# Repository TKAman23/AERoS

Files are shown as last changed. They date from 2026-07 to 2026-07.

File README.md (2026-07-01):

# AERoS
## An All-Encompassing Rocket System

[]()

A high-performance, compact rocket flight controller board designed around the **STM32F411RET6** microcontroller. This board integrates power management, sensor telemetry, state logging, and servo control into a single-cell Li-Po powered solution optimized for model rocketry and high-altitude aerospace tracking.

## **CRITICAL DISCLAIMER:**
*This board is currently in the active development phase. It has been fully routed and designed, but it has **NOT** been physically manufactured or bench-tested yet.*

## Board Previews & Renders

*(No 3D-models for L1, L2, and L3 were available)*

| Front 3D Render | Back 3D Render |
| :---: | :---: |
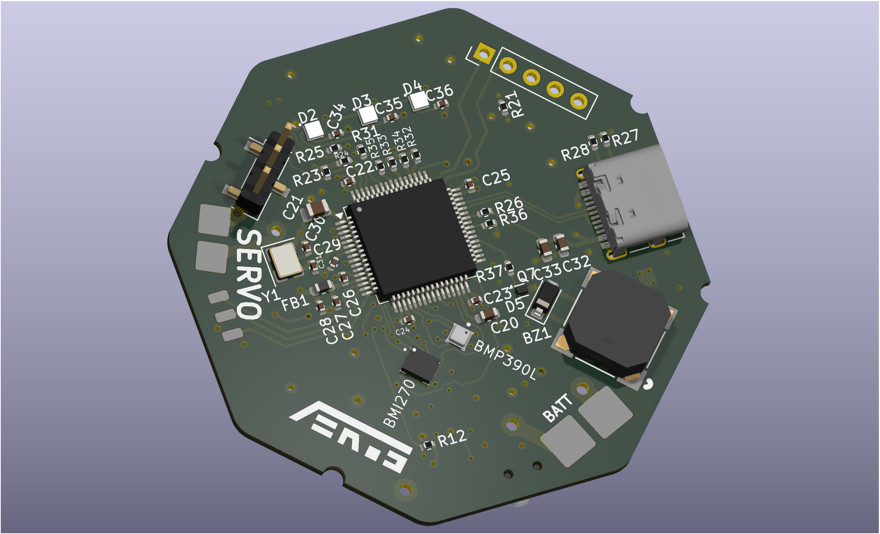
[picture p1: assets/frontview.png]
Board Front
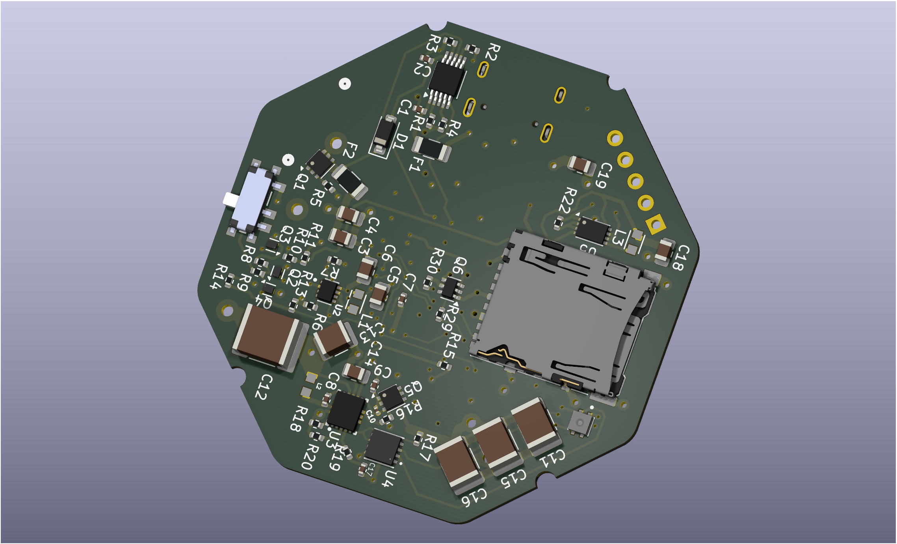
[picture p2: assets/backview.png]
Board Back
| <!-- Replace with your front render path e.g., ![Board Front](assets/front_render.png) -->  | <!-- Replace with your back render path e.g., ![Board Back](assets/back_render.png) -->  |

---

## 🛠Hardware & Board Specifications

### Core Processing & Power System
* **Microcontroller:** STM32F411RET6 (ARM Cortex-M4, 100MHz, 512KB Flash, 128KB SRAM).
* **Power Source:** Designed explicitly for a **Single-Cell Lithium-Polymer (Li-Po)** battery (~3.7V–4.2V).
* **USB Interface:** USB-C 2.0 interface supporting both data communication and **on-board USB battery charging**.
* **Power Switch:** Featuring a **self-latching MOSFET-based power switch** to enable digital soft-on/soft-off control or mechanical/pyrotechnic separation deployment triggers.
* **Actuator Power:** Integrated **Step-up (Boost) Converter** dedicated to delivering stable, elevated voltages required for servo actuation.

### Peripherals & User Interface
* **Indicators:** 3x Addressable/Configurable **RGB LEDs** for real-time state indication (e.g., pre-flight, armed, error, data logging active).
* **Acoustic Telemetry:** On-board **Piezo Buzzer** for audible flight readiness chirps, continuity checks, and recovery beacons.
* **Storage:** **D3AT SD Card Slot** wired via high-speed interface for high-rate blackbox flight logging.
* **Debugging:** Dedicated **ST-Link Connector** for SWD programming, flashing, and real-time debugging.

---

### System Architecture
<!-- Space for top-level or sheet-specific schematic screenshots as they relate to system blocks -->
```
   +-----------------------------------------------------------------+
   |                        USB-C 2.0 / Charger                      |
   +-----------------------------------------------------------------+
        |                           |
        v                           v
   +-------+           +-------------------------+           +-------+
   | Battery| ------>  | Self-Latching MOSFET SW |  -------> | Regs  |
   +-------+           +-------------------------+           +-------+
                                                                 |
            +-----------------------+------------+---------------|
            |                                    |               v
            v                                    v       +---------------+
   +-----------------+                  +------------+   | Servo Boost   |
   | STM32F411RET6   | <--- SPI/I2C --- | Sensor Bus |   +---------------+
   | Microcontroller |                  +------------+           |
   +-----------------+------+                                    v
    |      |        |       | ---------------------------> [ Servo Pins ]
    v      v        v       v
  [LEDs][Buzzer][SD Card][ST-Link]
```
For schematics, open the project file through KiCad 9.0 (can be found in the `board` directory)

<!-- #### Schematic Insights -->
<!-- <!-- Replace the placeholders below with cropped screenshots of your multi-sheet KiCad schematics -->
<!-- * **Power Management Sheet:** * *Includes USB charging circuit, battery protection, self-latching MOSFET stage, and the servo boost regulator.* -->
<!--     * <!-- ![Power Sheet](assets/schematic_power.png) --> **[Insert Power & Latching Schematic Screenshot Here]** -->
<!-- * **MCU & Breakouts Sheet:** -->
<!--     * *Includes STM32 pinouts, crystal oscillators, decoupling capacitors, and ST-Link header.* -->
<!--     * <!-- ![MCU Sheet](assets/schematic_mcu.png) --> **[Insert MCU Core Schematic Screenshot Here]** -->

---

## On-Board Sensors

The sensor suite communicates over optimized I2C/SPI buses to provide highly accurate 9-DOF inertial, environmental, and barometric data.

| Sensor Part Number | Type | Primary Flight Function |
| :--- | :--- | :--- |
| **BMI270** | 6-Axis IMU (Accel/Gyro) | Rocket orientation, acceleration profiling, launch detection, and apogee sensing. |
| **BMP390L** | High-Precision Barometer | Precise altitude tracking, descent-rate monitoring, and main/drogue parachute deployment triggering. |
| **SHTC3** | Humidity & Temp Sensor | Environmental monitoring and internal enclosure/payload bay diagnostics. |

---

## Design & Development

* **EDA Software:** Designed completely using **KiCad**.
* **Firmware Compatibility:** Perfect pairing with STM32CubeIDE, HAL libraries, or custom bare-metal C/C++ architectures.

### Future Scope / Additions (To-Do)
- [ ] Physical PCB manufacturing and assembly (PCBA evaluation).
- [ ] Continuity testing on the self-latching MOSFET network.
- [ ] Bench testing the Step-Up regulator under maximum servo load.
- [ ] Developing a comprehensive flight firmware stack (Blackbox logging framework, Kalman filtering for apogee detection).
- [ ] Pinout map cheat-sheet (Markdown table matching STM32 pins to hardware blocks).

---

## License & Copyright

This project is licensed under the **GNU GPL v3** License. 

```
Copyright (c) 2026 Karthikeya Turimalla (TKAman23)

This program is free software: you can redistribute it and/or modify
it under the terms of the GNU General Public License as published by
the Free Software Foundation, either version 3 of the License, or
(at your option) any later version.
```
See the accompanying `LICENSE` file for full terms and conditions.

---

## Attribution Request

If you use parts of this repository, please reference the repository, my username (TKAman23), or me (Karthikeya Turimalla) in your work.

---

## Contributing & Feedback

Since this project is in active prototyping, discussions, issues, and pull requests regarding optimization (especially around power management and thermal layout) are generally welcome!
Contact: [karthikeyaat@gmail.com](mailto:karthikeyaat@gmail.com).

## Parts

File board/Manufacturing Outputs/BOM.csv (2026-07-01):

Comment | Designator | Footprint | JLCPCB Part #
MLT-8530 | BZ1 | CustomLibrary2:MLT-8530_JHE | C94599
1u | C1,C2,C27,C28 | Capacitor_SMD:C_0402_1005Metric | C14445
4u7 | C3,C4,C14,C18 | Capacitor_SMD:C_0805_2012Metric | C1779
10u | C5,C6,C19,C21 | Capacitor_SMD:C_0805_2012Metric | C15850
100n | C7,C8,C9,C22,C23,C24,C25,C29 | Capacitor_SMD:C_0402_1005Metric | C1525
22n | C10 | Capacitor_SMD:C_0201_0603Metric | C285066
47u | C11,C15,C16 | Capacitor_SMD:C_1812_4532Metric | C342615
100u | C12 | Capacitor_SMD:C_2220_5750Metric | C76692
22u | C13 | Capacitor_SMD:C_1210_3225Metric | C52306
1n | C17 | Capacitor_SMD:C_0402_1005Metric | C1523
2u2 | C20 | Capacitor_SMD:C_0603_1608Metric | C23630
10n | C26 | Capacitor_SMD:C_0402_1005Metric | C1524
30p | C30,C31 | Capacitor_SMD:C_0402_1005Metric | C1570
10u | C32 | Capacitor_SMD:C_0603_1608Metric | C1691
4u7 | C33 | Capacitor_SMD:C_0603_1608Metric | C1705
220n | C34,C35,C36 | Capacitor_SMD:C_0402_1005Metric | C16772
SD101CW-E3-18 | D1,D5 | Diode_SMD:D_SOD-123 | C3313033
SK6805 | D2,D3,D4 | CustomLibrary2:SK6805-EC15 | C2890035
600m | F1 | Fuse:Fuse_1206_3216Metric | C2154056
500m | F2 | Fuse:Fuse_1206_3216Metric | C20798
GZ1608D121TF | FB1 | Inductor_SMD:L_0603_1608Metric | C12391
MountingHole | H1,H2,H3,H4 | MountingHole:MountingHole_2.2mm_M2
Conn_01x01_Pin | J1,J2 | CustomLibrary2:Pad_4x4mm
Conn_01x01_Pin | J3,J4 | CustomLibrary2:Pad_3x3mm
Conn_01x01_Pin | J5,J6,J7 | Connector_Wire:SolderWirePad_1x01_SMD_1x2mm
Conn_01x03_Pin | J8 | Connector_PinHeader_2.54mm:PinHeader_1x03_P2.54mm_Vertical_SMD_Pin1Left | C5160786
USB_C_Receptacle_USB2.0_14P | J9 | Connector_USB:USB_C_Receptacle_G-Switch_GT-USB-7010ASV | C2988369
Conn_01x05_Pin | J10 | Connector_PinHeader_2.54mm:PinHeader_1x05_P2.54mm_Vertical
SD Card Hirose DM3AT | J11 | Connector_Card:microSD_HC_Hirose_DM3AT-SF-PEJM5 | C114218
2u2 | L1,L3 | CustomLibrary2:IND_LQH2MPZ2R2MGRL | C2042050
1u | L2 | CustomLibrary2:0806 | C702824
PMOS | Q1,Q5 | CustomLibrary2:DFN-6-2EP_(AGM20P16AS) | C18221388
NMOS | Q2,Q3,Q4,Q7 | CustomLibrary2:DFN-3(0.6x1) | C20605534
NMOS | Q6 | Package_TO_SOT_SMD:SOT-363_SC-70-6 | C15215
1k | R1,R5,R8,R9,R23,R24,R29,R30,R32,R33,R34,R35,R36 | Resistor_SMD:R_0402_1005Metric | C11702
10k | R2,R3,R31 | Resistor_SMD:R_0402_1005Metric | C25744
1k5 | R4 | Resistor_SMD:R_0402_1005Metric | C25867
100k | R6,R11,R12,R13,R15,R26 | Resistor_SMD:R_0402_1005Metric | C25741
267k | R7 | Resistor_SMD:R_0402_1005Metric | C270622
100 | R10 | Resistor_SMD:R_0402_1005Metric | C25076
365k | R14 | Resistor_SMD:R_0402_1005Metric | C27006
121k | R16 | Resistor_SMD:R_0402_1005Metric | C11693
536k | R17 | Resistor_SMD:R_0402_1005Metric | C68457
300k | R18 | Resistor_SMD:R_0402_1005Metric | C25774
44k2 | R19 | Resistor_SMD:R_0402_1005Metric | C25895
78k7 | R20 | Resistor_SMD:R_0402_1005Metric | C67239
976k | R21 | Resistor_SMD:R_0402_1005Metric | C25802
562k | R22 | Resistor_SMD:R_0402_1005Metric | C48838
50k | R25 | Resistor_SMD:R_0402_1005Metric | C166559
5k1 | R27,R28 | Resistor_SMD:R_0402_1005Metric | C25905
470 | R37 | Resistor_SMD:R_0402_1005Metric | C25117
SW_SPDT | SW1 | CustomLibrary2:MK-12C02-G020_GSW | C963206
BQ24090DGQ | U1 | Package_SO:HVSSOP-10-1EP_3x3mm_P0.5mm_EP1.57x1.88mm_ThermalVias | C43306
TPS62840DLCR | U2 | CustomLibrary2:SON50P200X150X100-8N | C2071859
TPS611781RNWR | U3 | Custom_Library:RNW0013A | C2862009
MCP4552T-104E/MF | U4 | CustomLibrary2:DFN8_3x3MC_MCH | C623602
MCP1640x-xMC | U5 | Package_DFN_QFN:DFN-8-1EP_3x2mm_P0.5mm_EP1.75x1.45mm | C623037
STM32F411RET6 | U6 | Package_QFP:LQFP-64_10x10mm_P0.5mm | C94355
BMI270 | U7 | Custom_Library:XDCR_BMI270 | C2836813
BMP390L | U8 | Custom_Library:XDCR_BMP390L | C2684802
SHTC3 | U9 | Custom_Library:SON100P200X200X80-5N | C194656
16M | Y1 | Crystal:Crystal_SMD_3225-4Pin_3.2x2.5mm | C5452684

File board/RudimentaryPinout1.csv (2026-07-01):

Position | Name | Type | Signal | Label
1 | VBAT | Power
2 | PC13-ANTI_TAMP | I/O
3 | PC14-OSC32_IN | I/O
4 | PC15-OSC32_OUT | I/O
5 | PH0 - OSC_IN | I/O | RCC_OSC_IN
6 | PH1 - OSC_OUT | I/O | RCC_OSC_OUT
7 | NRST | Reset
8 | PC0 | I/O | ADC1_IN10
9 | PC1 | I/O
10 | PC2 | I/O
11 | PC3 | I/O
12 | VSSA | Power
13 | VDDA | Power
14 | PA0-WKUP | I/O | TIM2_CH1
15 | PA1 | I/O | TIM2_CH2
16 | PA2 | I/O | TIM2_CH3
17 | PA3 | I/O
18 | VSS | Power
19 | VDD | Power
20 | PA4 | I/O
21 | PA5 | I/O | SPI1_SCK
22 | PA6 | I/O | SPI1_MISO
23 | PA7 | I/O | SPI1_MOSI
24 | PC4 | I/O
25 | PC5 | I/O
26 | PB0 | I/O
27 | PB1 | I/O
28 | PB2 | I/O
29 | PB10 | I/O
30 | VCAP1 | Power
31 | VSS | Power
32 | VDD | Power
33 | PB12 | I/O
34 | PB13 | I/O
35 | PB14 | I/O
36 | PB15 | I/O
37 | PC6 | I/O | TIM3_CH1
38 | PC7 | I/O | TIM3_CH2
39 | PC8 | I/O | SDIO_D0
40 | PC9 | I/O | SDIO_D1
41 | PA8 | I/O
42 | PA9 | I/O | USB_OTG_FS_VBUS
43 | PA10 | I/O
44 | PA11 | I/O | USB_OTG_FS_DM
45 | PA12 | I/O | USB_OTG_FS_DP
46 | PA13 | I/O | SYS_JTMS-SWDIO
47 | VSS | Power
48 | VDD | Power
49 | PA14 | I/O | SYS_JTCK-SWCLK
50 | PA15 | I/O
51 | PC10 | I/O | SDIO_D2
52 | PC11 | I/O | SDIO_D3
53 | PC12 | I/O | SDIO_CK
54 | PD2 | I/O | SDIO_CMD
55 | PB3 | I/O
56 | PB4 | I/O
57 | PB5 | I/O
58 | PB6 | I/O | I2C1_SCL
59 | PB7 | I/O | I2C1_SDA
60 | BOOT0 | Boot
61 | PB8 | I/O
62 | PB9 | I/O
63 | VSS | Power
64 | VDD | Power

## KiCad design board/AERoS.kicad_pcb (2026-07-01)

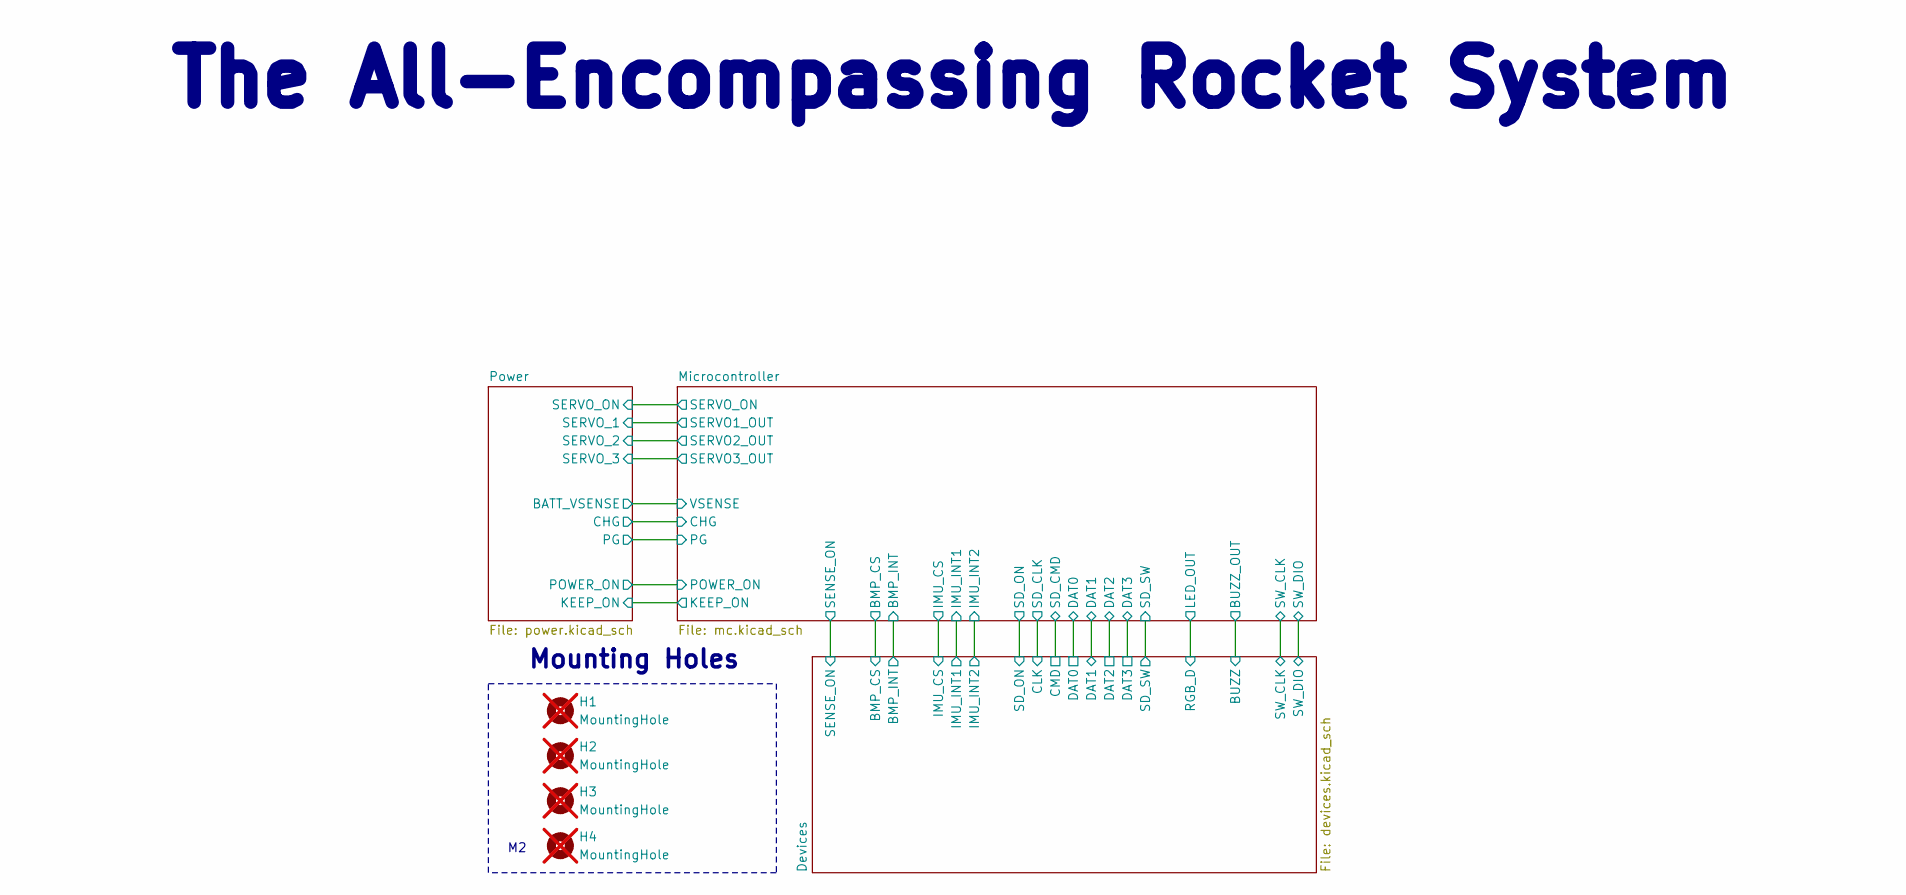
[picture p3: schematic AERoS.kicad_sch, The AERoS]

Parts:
H1, H2, H3, H4: MountingHole; MountingHole_2.2mm_M2; not fitted

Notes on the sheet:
Mounting Holes
The All-Encompassing Rocket System

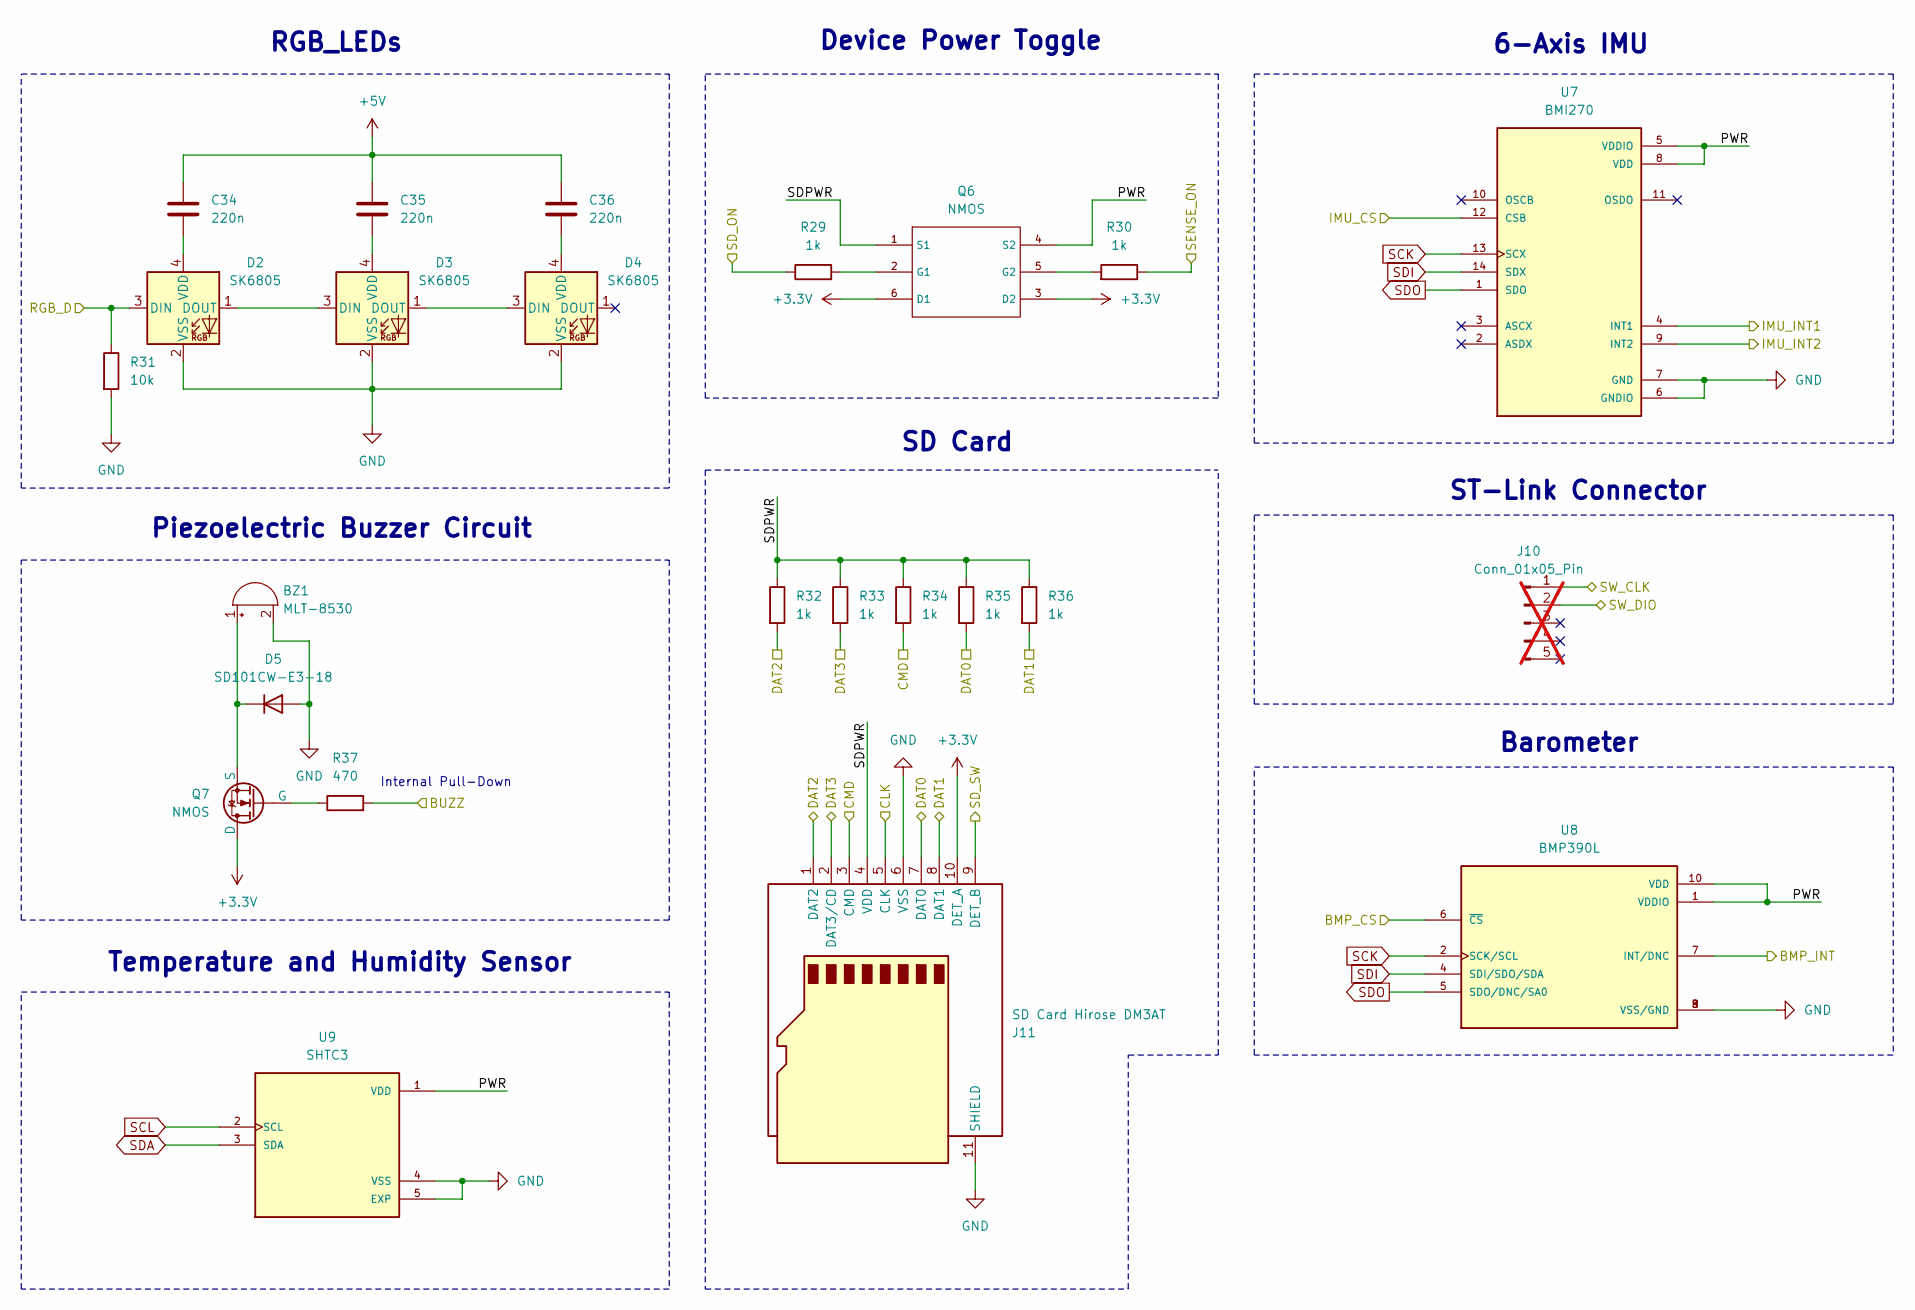
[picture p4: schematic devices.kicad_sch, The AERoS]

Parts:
BZ1: MLT-8530; MLT-8530_JHE; MFR. Part # MLT-8530; JLCPCB Part # C94599
C34, C35, C36: 220n; C_0402_1005Metric; MFR. Part # CL05B224KO5NNNC; JLCPCB Part # C16772
D2, D3, D4: SK6805; SK6805-EC15; MFR. Part # SK6805-EC15; JLCPCB Part # C2890035
D5: SD101CW-E3-18; D_SOD-123; MFR. Part # SD101CW-E3-18; JLCPCB Part # C3313033
J10: Conn_01x05_Pin; PinHeader_1x05_P2.54mm_Vertical; not fitted
J11: SD Card Hirose DM3AT; microSD_HC_Hirose_DM3AT-SF-PEJM5; MFR. Part # DM3AT-SF-PEJM5; JLCPCB Part # C114218
Q6: NMOS; SOT-363_SC-70-6; MFR. Part # NTJD5121NT1G; JLCPCB Part # C15215
Q7: NMOS; DFN-3(0.6x1); MFR. Part # YJA3134KB; JLCPCB Part # C20605534
R29, R30, R32, R33, R34, R35, R36: 1k; R_0402_1005Metric; MFR. Part # 0402WGF1001TCE; JLCPCB Part # C11702
R31: 10k; R_0402_1005Metric; MFR. Part # 0402WGF1002TCE; JLCPCB Part # C25744
R37: 470; R_0402_1005Metric; MFR. Part # 0402WGF4700TCE; JLCPCB Part # C25117
U7: BMI270; XDCR_BMI270; MFR. Part # BMI270; JLCPCB Part # C2836813
U8: BMP390L; XDCR_BMP390L; PARTREV 1.7; JLCPCB Part # C2684802
U9: SHTC3; SON100P200X200X80-5N; PARTREV 3; JLCPCB Part # C194656

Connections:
+3.3V: J11.10 (DET_A), Q6.3 (D2), Q6.6 (D1), Q7.1 (D); also elsewhere on the board
+5V: C34.1, C35.1, C36.1; also elsewhere on the board
/Devices/BMP_CS: U8.6 (~CS); also elsewhere on the board
/Devices/BMP_INT: U8.7 (INT/DNC); also elsewhere on the board
/Devices/BUZZ: R37.2; also elsewhere on the board
/Devices/CLK: J11.5 (CLK); also elsewhere on the board
/Devices/CMD: J11.3 (CMD), R34.2; also elsewhere on the board
/Devices/DAT0: J11.7 (DAT0), R35.2; also elsewhere on the board
/Devices/DAT1: J11.8 (DAT1), R36.2; also elsewhere on the board
/Devices/DAT2: J11.1 (DAT2), R32.2; also elsewhere on the board
/Devices/DAT3: J11.2 (DAT3/CD), R33.2; also elsewhere on the board
/Devices/IMU_CS: U7.12 (CSB); also elsewhere on the board
/Devices/IMU_INT1: U7.4 (INT1); also elsewhere on the board
/Devices/IMU_INT2: U7.9 (INT2); also elsewhere on the board
/Devices/PWR: Q6.4 (S2), U7.5 (VDDIO), U7.8 (VDD), U8.1 (VDDIO), U8.10 (VDD), U9.1 (VDD)
/Devices/RGB_D: D2.3 (DIN), R31.1; also elsewhere on the board
/Devices/SDPWR: J11.4 (VDD), Q6.1 (S1), R32.1, R33.1, R34.1, R35.1, R36.1
/Devices/SD_ON: R29.1; also elsewhere on the board
/Devices/SD_SW: J11.9 (DET_B); also elsewhere on the board
/Devices/SENSE_ON: R30.1; also elsewhere on the board
/Devices/SW_CLK: J10.1; also elsewhere on the board
/Devices/SW_DIO: J10.2; also elsewhere on the board
GND: BZ1.2 (-), D2.2 (VSS), D3.2 (VSS), D4.2 (VSS), D5.2 (A), J11.6 (VSS), J11.11 (SHIELD), R31.2, U7.6 (GNDIO), U7.7 (GND), U8.3 (VSS/GND), U8.8 (VSS/GND), U8.9 (VSS/GND), U9.4 (VSS), U9.5 (EXP); also elsewhere on the board
unnamed: BZ1.1 (+), D5.1 (K), Q7.3 (S)
unnamed: D2.1 (DOUT), D3.3 (DIN)
unnamed: C34.2, D2.4 (VDD)
unnamed: D3.1 (DOUT), D4.3 (DIN)
unnamed: C35.2, D3.4 (VDD)
unnamed: C36.2, D4.4 (VDD)
unnamed: Q6.2 (G1), R29.2
unnamed: Q6.5 (G2), R30.2
unnamed: Q7.2 (G), R37.1
SCK: U7.13 (SCX), U8.2 (SCK/SCL); also elsewhere on the board
SCL: U9.2 (SCL); also elsewhere on the board
SDA: U9.3 (SDA); also elsewhere on the board
SDI: U7.14 (SDX), U8.4 (SDI/SDO/SDA); also elsewhere on the board
SDO: U7.1 (SDO), U8.5 (SDO/DNC/SA0); also elsewhere on the board

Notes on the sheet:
RGB_LEDs
6-Axis IMU
Internal Pull-Down
Device Power Toggle
Barometer
Piezoelectric Buzzer Circuit
Temperature and Humidity Sensor
SD Card
ST-Link Connector

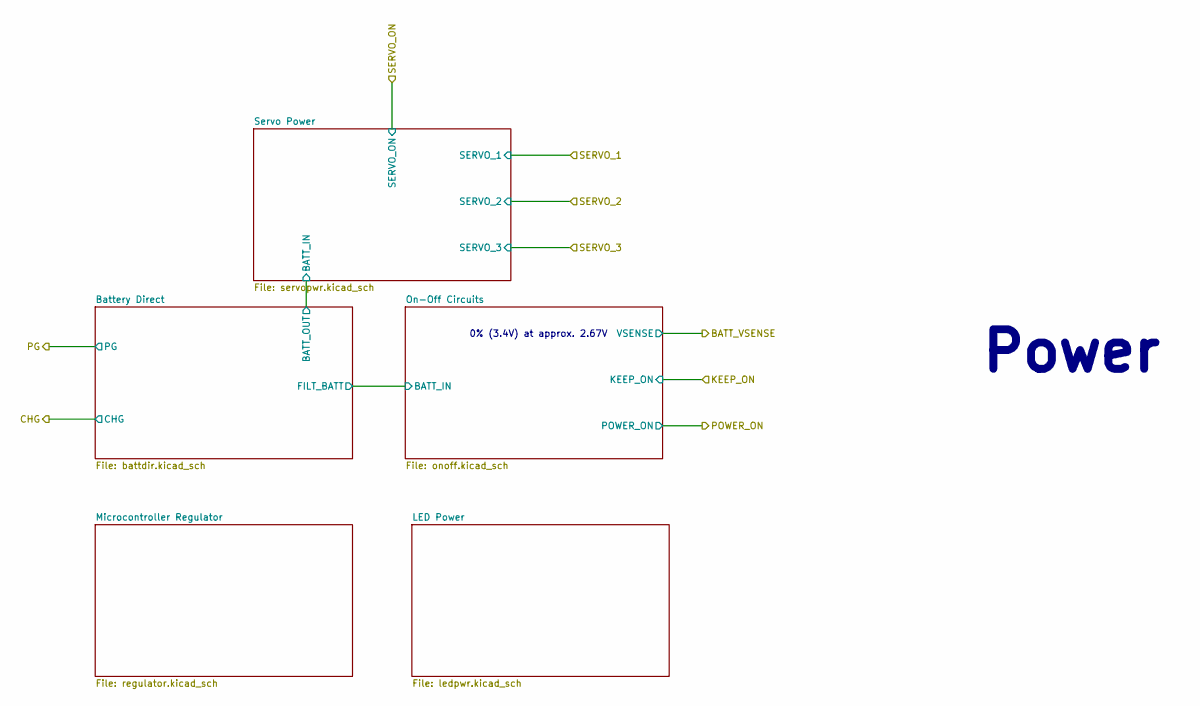
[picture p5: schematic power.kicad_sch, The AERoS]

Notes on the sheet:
Power
0% (3.4V) at approx. 2.67V

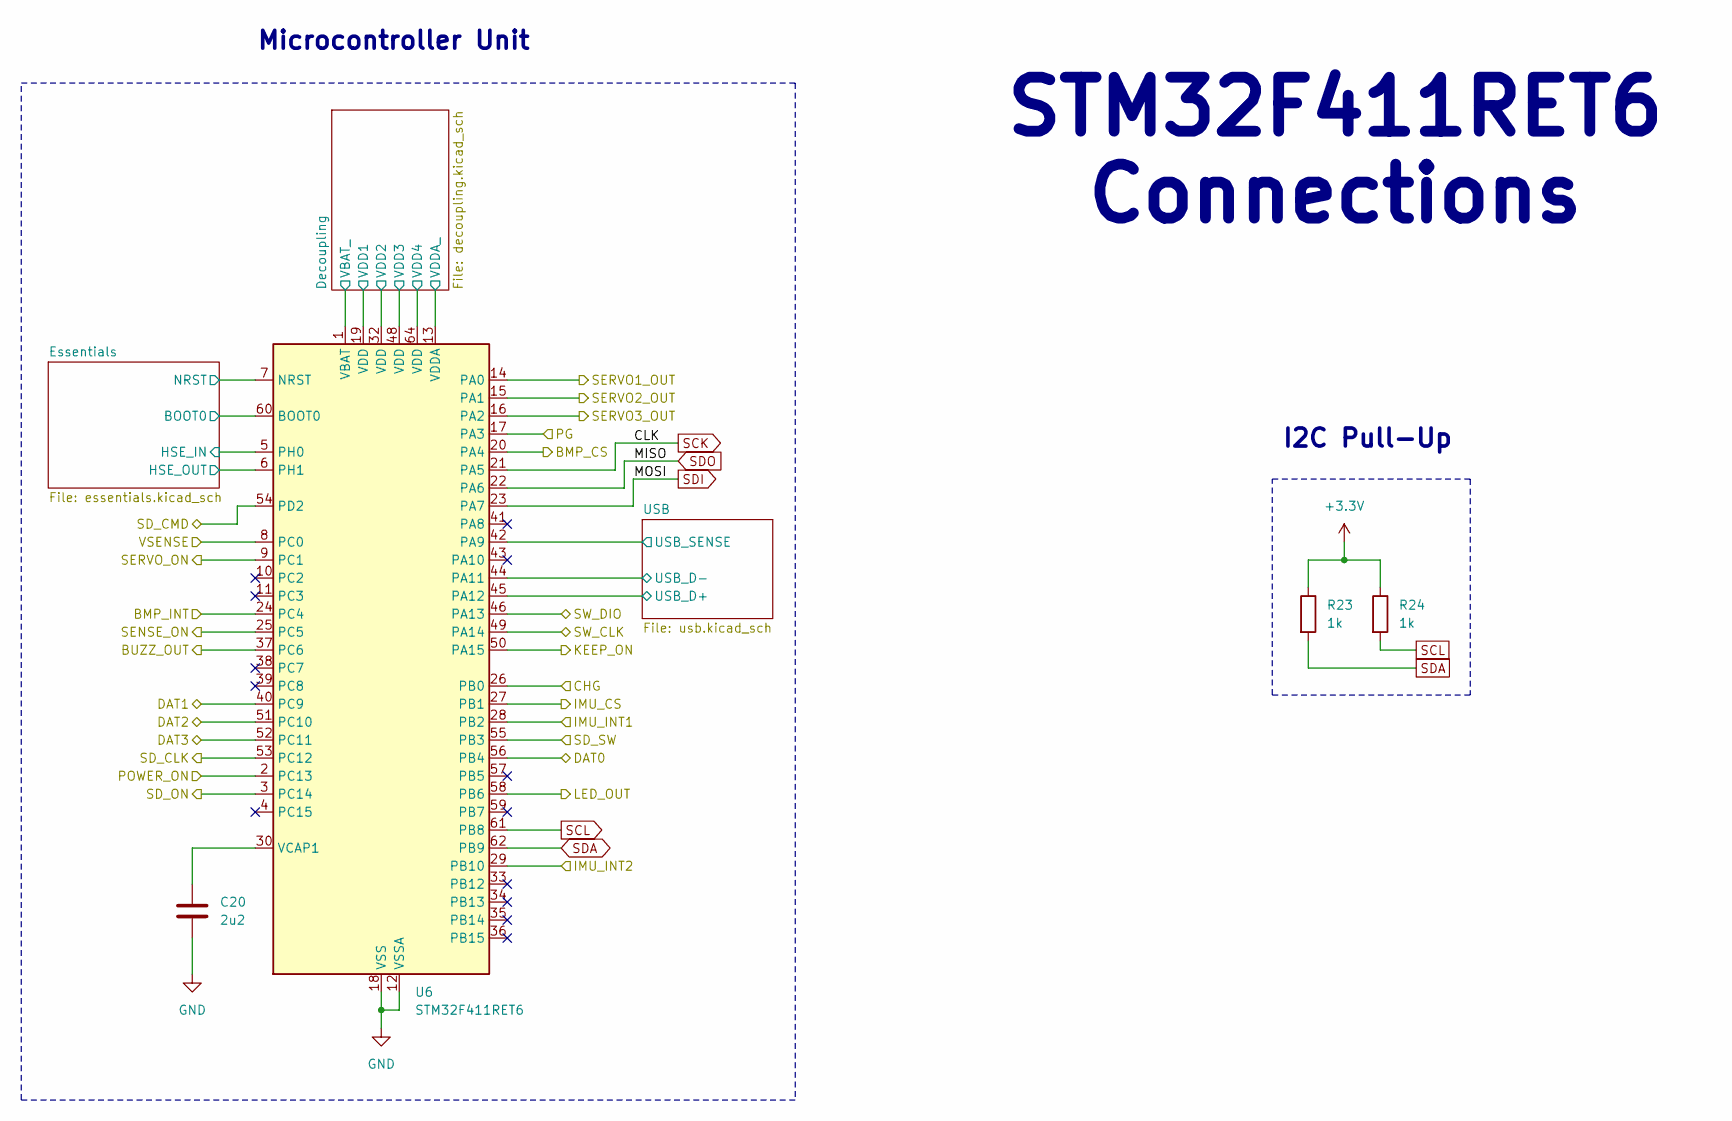
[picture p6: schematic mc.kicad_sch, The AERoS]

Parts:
C20: 2u2; C_0603_1608Metric; MFR. Part # CL10A225KO8NNNC; JLCPCB Part # C23630
R23, R24: 1k; R_0402_1005Metric; MFR. Part # 0402WGF1001TCE; JLCPCB Part # C11702
U6: STM32F411RET6; LQFP-64_10x10mm_P0.5mm; MFR. Part # STM32F411RET6; JLCPCB Part # C94355

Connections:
+3.3V: R23.1, R24.1, U6.1 (VBAT), U6.19 (VDD), U6.32 (VDD), U6.48 (VDD), U6.64 (VDD); also elsewhere on the board
/Devices/BMP_CS: U6.20 (PA4); also elsewhere on the board
/Devices/BMP_INT: U6.24 (PC4); also elsewhere on the board
/Devices/BUZZ: U6.37 (PC6); also elsewhere on the board
/Devices/CLK: U6.53 (PC12); also elsewhere on the board
/Devices/CMD: U6.54 (PD2); also elsewhere on the board
/Devices/DAT0: U6.56 (PB4); also elsewhere on the board
/Devices/DAT1: U6.40 (PC9); also elsewhere on the board
/Devices/DAT2: U6.51 (PC10); also elsewhere on the board
/Devices/DAT3: U6.52 (PC11); also elsewhere on the board
/Devices/IMU_CS: U6.27 (PB1); also elsewhere on the board
/Devices/IMU_INT1: U6.28 (PB2); also elsewhere on the board
/Devices/IMU_INT2: U6.29 (PB10); also elsewhere on the board
/Devices/RGB_D: U6.58 (PB6); also elsewhere on the board
/Devices/SD_ON: U6.3 (PC14); also elsewhere on the board
/Devices/SD_SW: U6.55 (PB3); also elsewhere on the board
/Devices/SENSE_ON: U6.25 (PC5); also elsewhere on the board
/Devices/SW_CLK: U6.49 (PA14); also elsewhere on the board
/Devices/SW_DIO: U6.46 (PA13); also elsewhere on the board
/Microcontroller/CHG: U6.26 (PB0); also elsewhere on the board
/Microcontroller/Decoupling/VDDA_: U6.13 (VDDA); also elsewhere on the board
/Microcontroller/Essentials/BOOT0: U6.60 (BOOT0); also elsewhere on the board
/Microcontroller/Essentials/HSE_IN: U6.5 (PH0); also elsewhere on the board
/Microcontroller/Essentials/HSE_OUT: U6.6 (PH1); also elsewhere on the board
/Microcontroller/Essentials/NRST: U6.7 (NRST); also elsewhere on the board
/Microcontroller/KEEP_ON: U6.50 (PA15); also elsewhere on the board
/Microcontroller/PG: U6.17 (PA3); also elsewhere on the board
/Microcontroller/POWER_ON: U6.2 (PC13); also elsewhere on the board
/Microcontroller/SERVO1_OUT: U6.14 (PA0); also elsewhere on the board
/Microcontroller/SERVO2_OUT: U6.15 (PA1); also elsewhere on the board
/Microcontroller/SERVO3_OUT: U6.16 (PA2); also elsewhere on the board
/Microcontroller/SERVO_ON: U6.9 (PC1); also elsewhere on the board
/Microcontroller/USB/USB_D+: U6.45 (PA12); also elsewhere on the board
/Microcontroller/USB/USB_D-: U6.44 (PA11); also elsewhere on the board
/Microcontroller/USB/USB_SENSE: U6.42 (PA9); also elsewhere on the board
/Microcontroller/VSENSE: U6.8 (PC0); also elsewhere on the board
GND: C20.2, U6.12 (VSSA), U6.18 (VSS), U6.31 (VSS), U6.47 (VSS), U6.63 (VSS); also elsewhere on the board
unnamed: C20.1, U6.30 (VCAP1)
SCK: U6.21 (PA5); also elsewhere on the board
SCL: R24.2, U6.61 (PB8); also elsewhere on the board
SDA: R23.2, U6.62 (PB9); also elsewhere on the board
SDI: U6.23 (PA7); also elsewhere on the board
SDO: U6.22 (PA6); also elsewhere on the board

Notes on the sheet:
I2C Pull-Up
Microcontroller Unit
STM32F411RET6 Connections

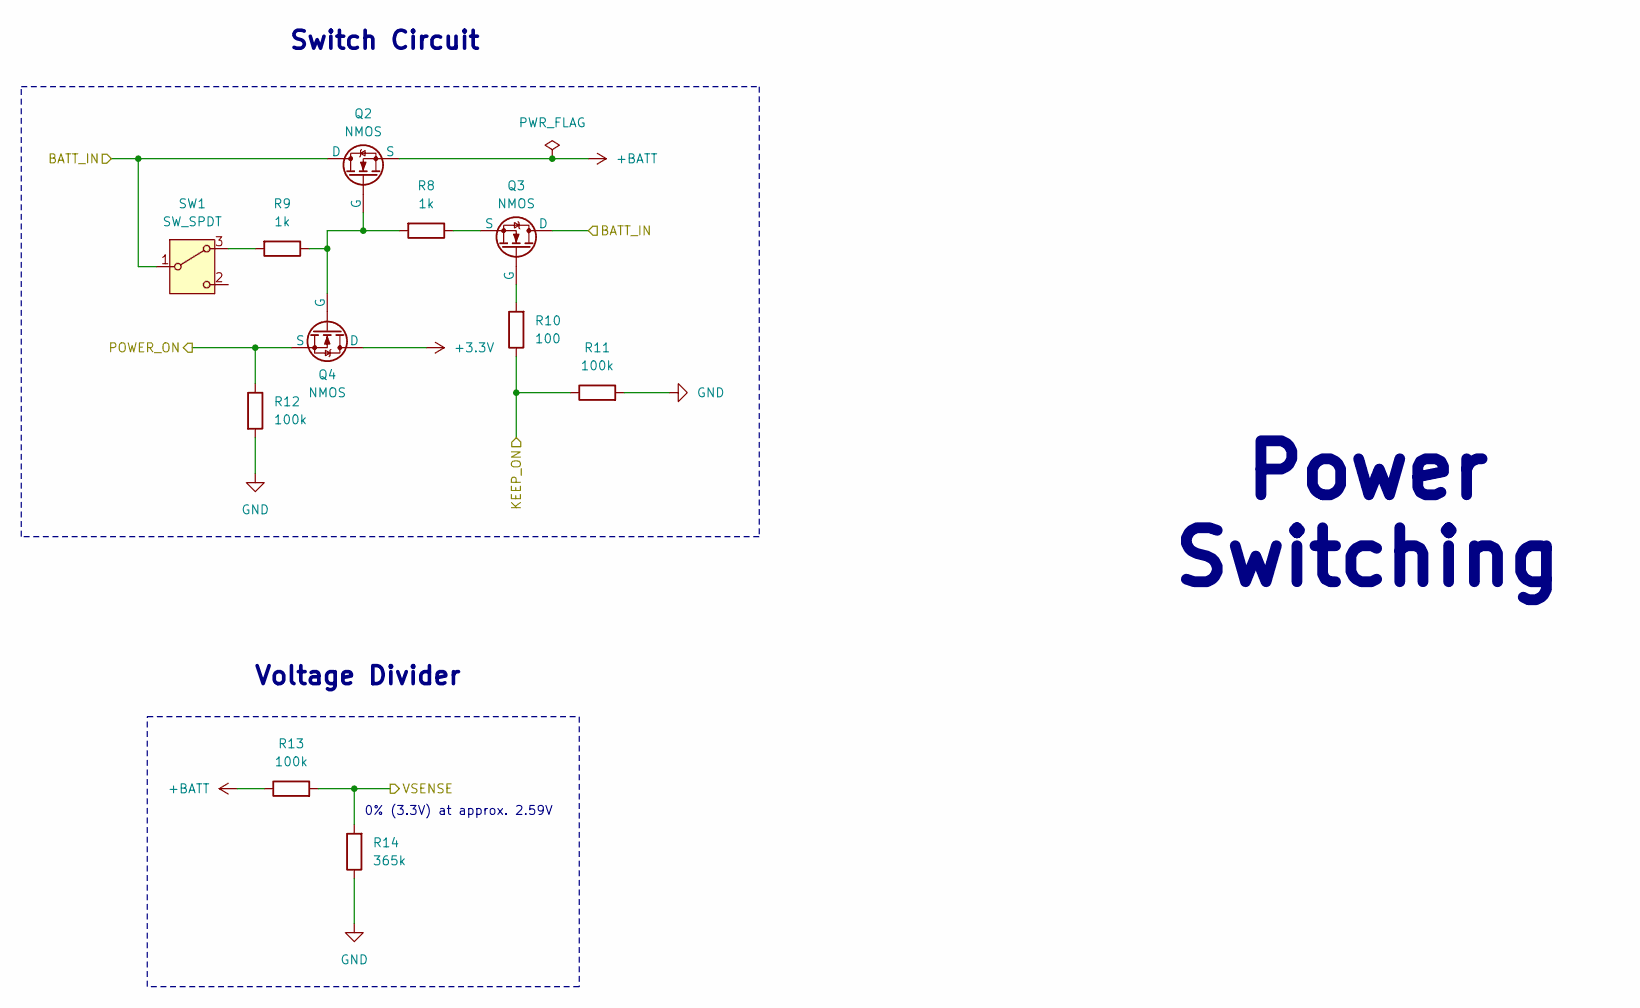
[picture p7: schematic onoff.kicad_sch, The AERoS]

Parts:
Q2, Q3, Q4: NMOS; DFN-3(0.6x1); MFR. Part # YJA3134KB; JLCPCB Part # C20605534
R8, R9: 1k; R_0402_1005Metric; MFR. Part # 0402WGF1001TCE; JLCPCB Part # C11702
R10: 100; R_0402_1005Metric; MFR. Part # 0402WGF1000TCE; JLCPCB Part # C25076
R11, R12, R13: 100k; R_0402_1005Metric; MFR. Part # 0402WGF1003TCE; JLCPCB Part # C25741
R14: 365k; R_0402_1005Metric; MFR. Part # 0402WGF3653TCE; JLCPCB Part # C27006
SW1: SW_SPDT; MK-12C02-G020_GSW; MFR. Part # MK-12C02-G020_GSW; JLCPCB Part # C963206

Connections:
+3.3V: Q4.1 (D); also elsewhere on the board
+BATT: Q2.3 (S), R13.1; also elsewhere on the board
/Microcontroller/KEEP_ON: R10.1, R11.1; also elsewhere on the board
/Microcontroller/POWER_ON: Q4.3 (S), R12.1; also elsewhere on the board
/Microcontroller/VSENSE: R13.2, R14.2; also elsewhere on the board
/Power/Battery Direct/FILT_BATT: Q2.1 (D), Q3.1 (D), SW1.1 (B); also elsewhere on the board
GND: R11.2, R12.2, R14.1; also elsewhere on the board
unnamed: Q2.2 (G), Q4.2 (G), R8.2, R9.1
unnamed: Q3.2 (G), R10.2
unnamed: Q3.3 (S), R8.1
unnamed: R9.2, SW1.3 (A)

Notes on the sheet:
Power Switching
0% (3.3V) at approx. 2.59V
Switch Circuit
Voltage Divider

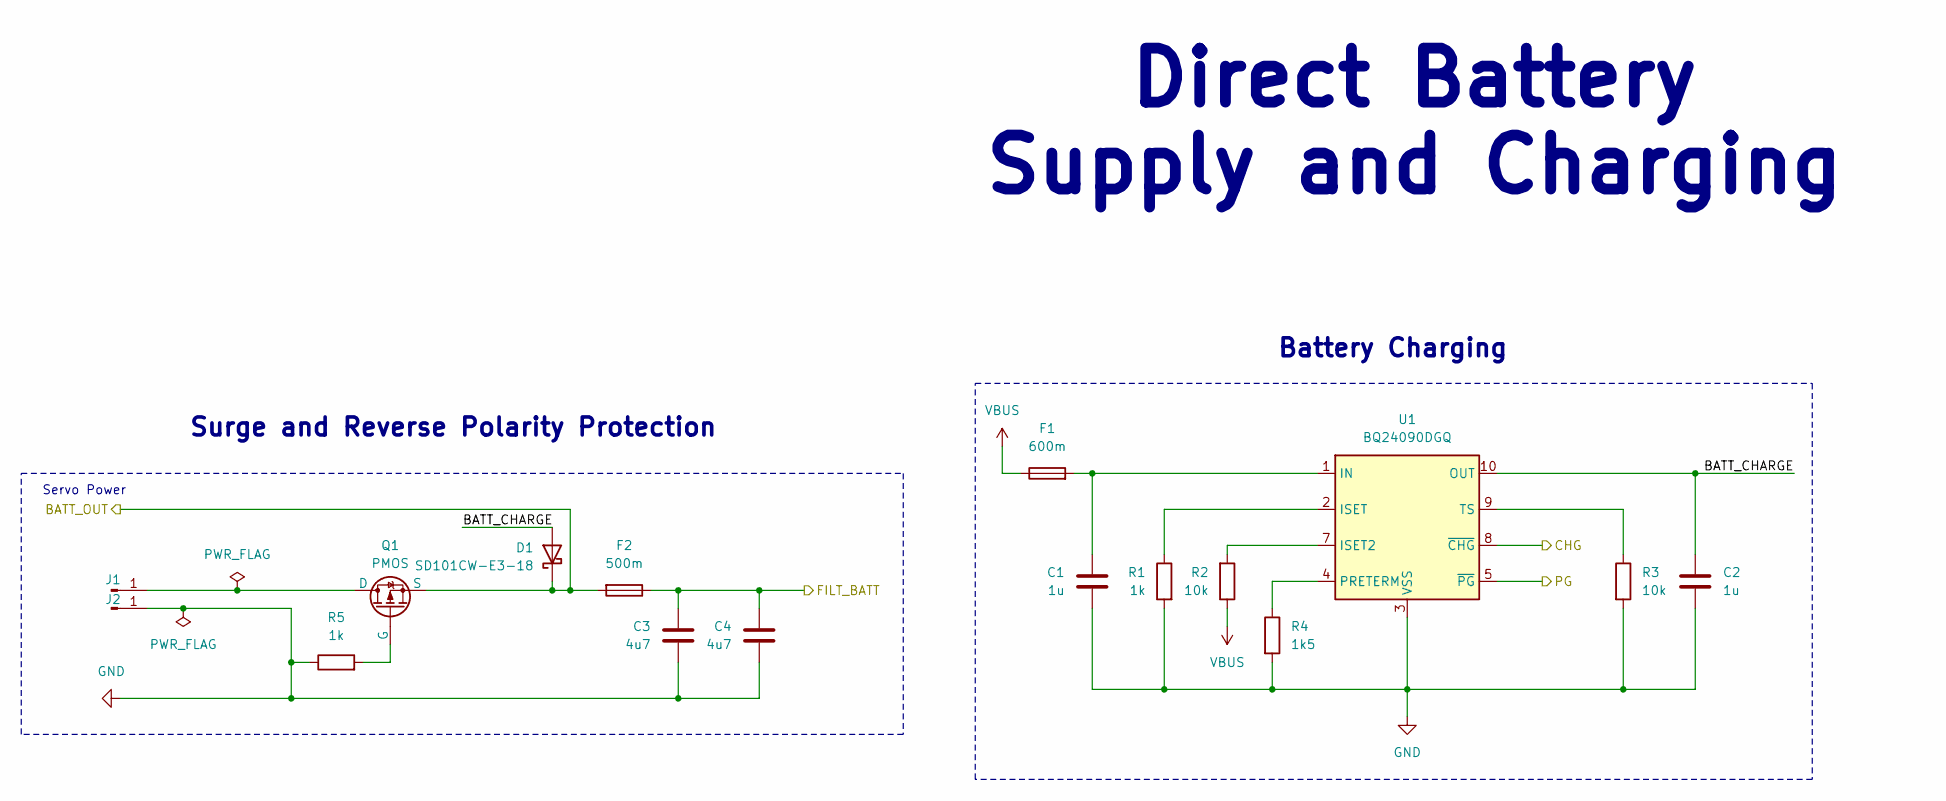
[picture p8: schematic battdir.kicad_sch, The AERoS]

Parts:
C1, C2: 1u; C_0402_1005Metric; MFR. Part # CL05A105KP5NNNC; JLCPCB Part # C14445
C3, C4: 4u7; C_0805_2012Metric; MFR. Part # CL21A475KAQNNNE; JLCPCB Part # C1779
D1: SD101CW-E3-18; D_SOD-123; MFR. Part # SD101CW-E3-18; JLCPCB Part # C3313033
F1: 600m; Fuse_1206_3216Metric; MFR. Part # 1206L050/24WR; JLCPCB Part # C2154056
F2: 500m; Fuse_1206_3216Metric; MFR. Part # SMD1206P025TF; JLCPCB Part # C20798
J1, J2: Conn_01x01_Pin; Pad_4x4mm
Q1: PMOS; DFN-6-2EP_(AGM20P16AS); MFR. Part # AGM20P16AS; JLCPCB Part # C18221388
R1, R5: 1k; R_0402_1005Metric; MFR. Part # 0402WGF1001TCE; JLCPCB Part # C11702
R2, R3: 10k; R_0402_1005Metric; MFR. Part # 0402WGF1002TCE; JLCPCB Part # C25744
R4: 1k5; R_0402_1005Metric; MFR. Part # 0402WGF1501TCE; JLCPCB Part # C25867
U1: BQ24090DGQ; HVSSOP-10-1EP_3x3mm_P0.5mm_EP1.57x1.88mm_ThermalVias; MFR. Part # BQ24090DGQR; JLCPCB Part # C43306

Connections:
/Microcontroller/CHG: U1.8 (~CHG); also elsewhere on the board
/Microcontroller/PG: U1.5 (~PG); also elsewhere on the board
/Power/Battery Direct/BATT_CHARGE: C2.1, D1.2 (A), U1.10 (OUT)
/Power/Battery Direct/BATT_OUT: D1.1 (K), F2.2, Q1.3 (S); also elsewhere on the board
/Power/Battery Direct/FILT_BATT: C3.2, C4.2, F2.1; also elsewhere on the board
GND: C1.2, C2.2, C3.1, C4.1, J2.1, R1.2, R3.2, R4.2, R5.1, U1.3 (VSS), U1.11 (VSS); also elsewhere on the board
unnamed: J1.1, Q1.1 (D)
unnamed: Q1.2 (G), R5.2
unnamed: C1.1, F1.2, U1.1 (IN)
unnamed: R2.2, U1.7 (ISET2)
unnamed: R1.1, U1.2 (ISET)
unnamed: R4.1, U1.4 (PRETERM)
unnamed: R3.1, U1.9 (TS)
VBUS: F1.1, R2.1; also elsewhere on the board

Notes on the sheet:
Battery Charging
Surge and Reverse Polarity Protection
Direct Battery Supply and Charging
Servo Power

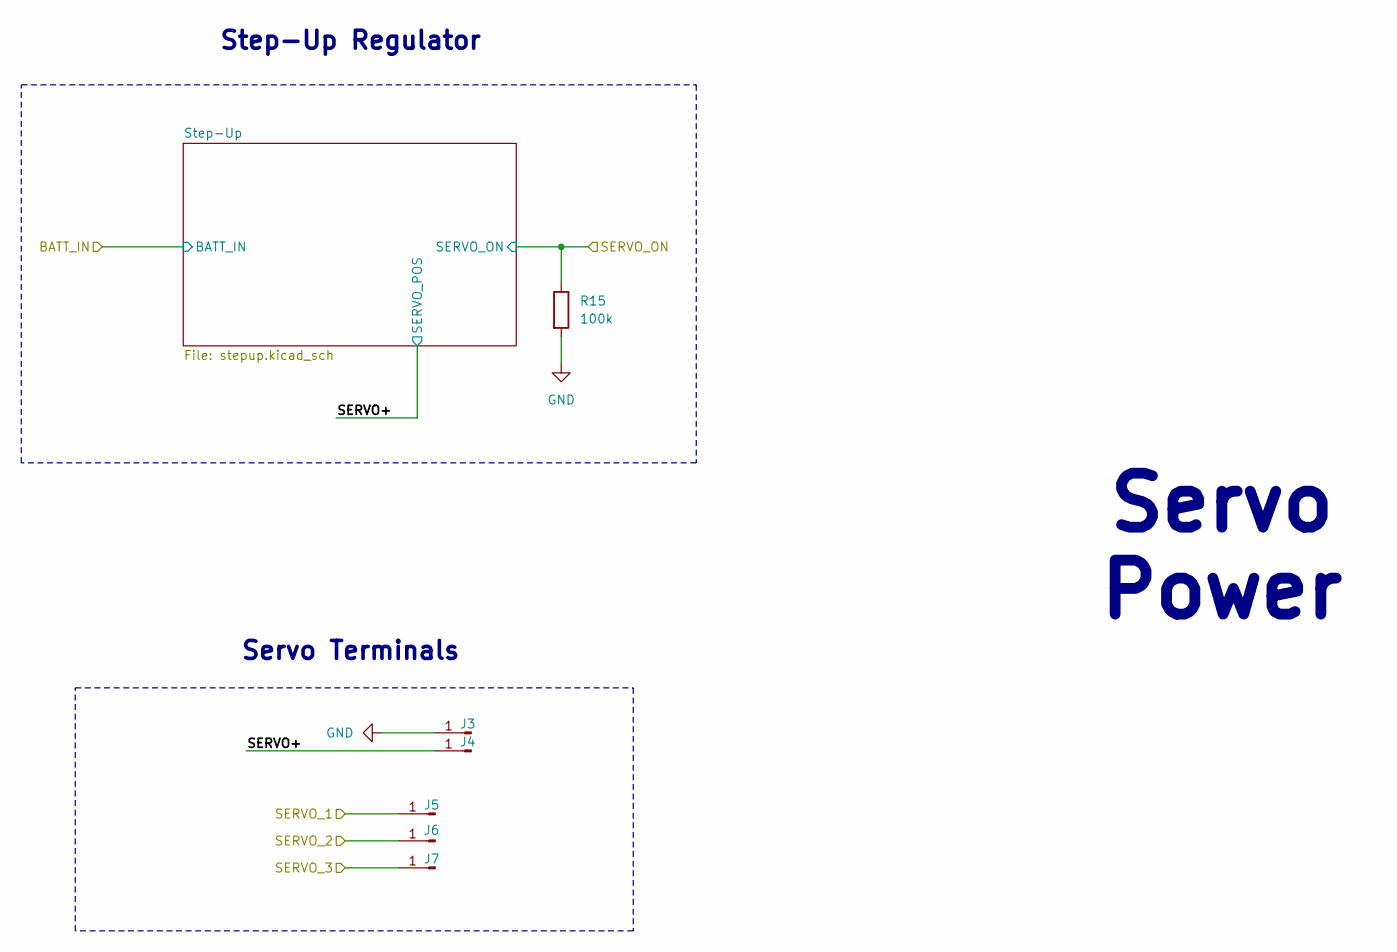
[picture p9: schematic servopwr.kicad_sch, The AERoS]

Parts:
J3, J4: Conn_01x01_Pin; Pad_3x3mm
J5, J6, J7: Conn_01x01_Pin; SolderWirePad_1x01_SMD_1x2mm
R15: 100k; R_0402_1005Metric; MFR. Part # 0402WGF1003TCE; JLCPCB Part # C25741

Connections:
/Microcontroller/SERVO1_OUT: J5.1; also elsewhere on the board
/Microcontroller/SERVO2_OUT: J6.1; also elsewhere on the board
/Microcontroller/SERVO3_OUT: J7.1; also elsewhere on the board
/Microcontroller/SERVO_ON: R15.1; also elsewhere on the board
/Power/Servo Power/SERVO+: J4.1; also elsewhere on the board
GND: J3.1, R15.2; also elsewhere on the board

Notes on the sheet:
Step-Up Regulator
Servo Power
Servo Terminals

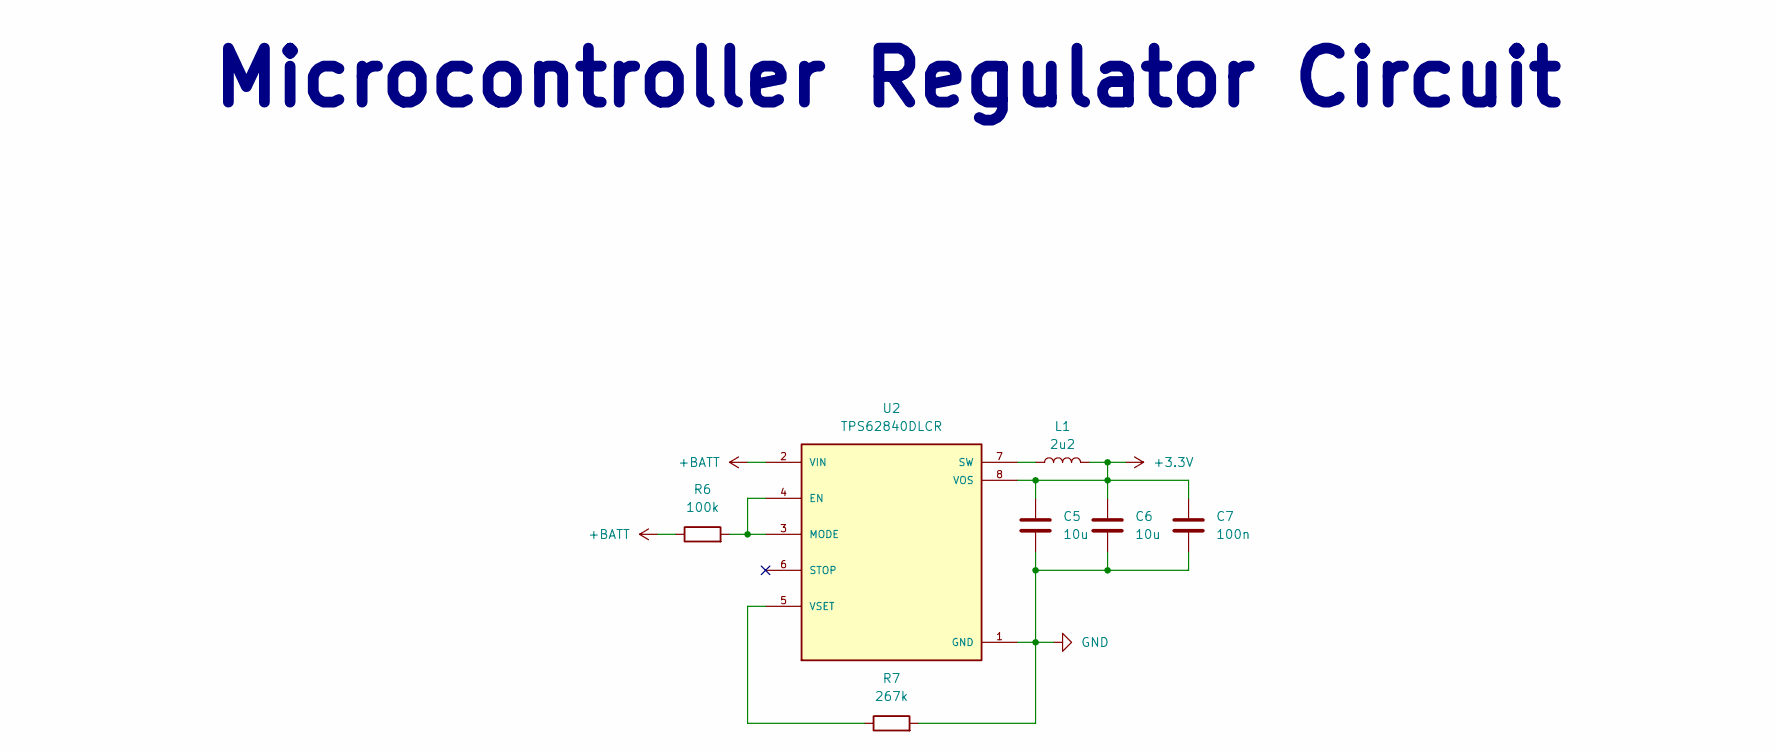
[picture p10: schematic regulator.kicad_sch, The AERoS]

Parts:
C5, C6: 10u; C_0805_2012Metric; MFR. Part # CL21A106KAYNNNE; JLCPCB Part # C15850
C7: 100n; C_0402_1005Metric; MFR. Part # CL05B104KO5NNNC; JLCPCB Part # C1525
L1: 2u2; IND_LQH2MPZ2R2MGRL; MFR. Part # LQH2MPZ2R2MGRL; JLCPCB Part # C2042050
R6: 100k; R_0402_1005Metric; MFR. Part # 0402WGF1003TCE; JLCPCB Part # C25741
R7: 267k; R_0402_1005Metric; MFR. Part # 0402WGF2673TCE; JLCPCB Part # C270622
U2: TPS62840DLCR; SON50P200X150X100-8N; MFR. Part # TPS62840DLCR; JLCPCB Part # C2071859

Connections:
+3.3V: C5.2, C6.2, C7.2, L1.2, U2.8 (VOS); also elsewhere on the board
+BATT: R6.1, U2.2 (VIN); also elsewhere on the board
GND: C5.1, C6.1, C7.1, R7.2, U2.1 (GND); also elsewhere on the board
unnamed: R6.2, U2.3 (MODE), U2.4 (EN)
unnamed: L1.1, U2.7 (SW)
unnamed: R7.1, U2.5 (VSET)

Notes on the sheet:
Microcontroller Regulator Circuit

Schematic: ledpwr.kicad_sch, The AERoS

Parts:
C18: 4u7; C_0805_2012Metric; MFR. Part # CL21A475KAQNNNE; JLCPCB Part # C1779
C19: 10u; C_0805_2012Metric; MFR. Part # CL21A106KAYNNNE; JLCPCB Part # C15850
L3: 2u2; IND_LQH2MPZ2R2MGRL; MFR. Part # LQH2MPZ2R2MGRL; JLCPCB Part # C2042050
R21: 976k; R_0402_1005Metric; MFR. Part # 0402WGF9763TCE; JLCPCB Part # C25802
R22: 562k; R_0402_1005Metric; MFR. Part # 0402WGF5623TCE; JLCPCB Part # C48838
U5: MCP1640x-xMC; DFN-8-1EP_3x2mm_P0.5mm_EP1.75x1.45mm; MFR. Part # MCP1640CT-I/MC; JLCPCB Part # C623037

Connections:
+5V: C19.1, R21.1, U5.6 (V_{OUT}), U5.7 (V_{OUT}); also elsewhere on the board
+BATT: C18.1, L3.1, U5.4 (EN), U5.8 (V_{IN}); also elsewhere on the board
GND: C18.2, C19.2, R22.2, U5.2 (GND), U5.3 (GND), U5.9 (GND); also elsewhere on the board
unnamed: L3.2, U5.5 (SW)
unnamed: R21.2, R22.1, U5.1 (V_{FB})

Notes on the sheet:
LED Power Regulator
LED Regulator

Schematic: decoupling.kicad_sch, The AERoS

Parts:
C21: 10u; C_0805_2012Metric; MFR. Part # CL21A106KAYNNNE; JLCPCB Part # C15850
C22, C23, C24, C25: 100n; C_0402_1005Metric; MFR. Part # CL05B104KO5NNNC; JLCPCB Part # C1525
C26: 10n; C_0402_1005Metric; MFR. Part # 0402B103K500NT; JLCPCB Part # C1524
C27, C28: 1u; C_0402_1005Metric; MFR. Part # CL05A105KP5NNNC; JLCPCB Part # C14445
FB1: GZ1608D121TF; L_0603_1608Metric; MFR. Part # GZ1608D121TF; JLCPCB Part # C12391

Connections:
+3.3V: C21.1, C22.1, C23.1, C24.1, C25.1, C28.1, FB1.2; also elsewhere on the board
/Microcontroller/Decoupling/VDDA_: C26.1, C27.1, FB1.1; also elsewhere on the board
GND: C21.2, C22.2, C23.2, C24.2, C25.2, C26.2, C27.2, C28.2; also elsewhere on the board

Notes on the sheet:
Analog
Decoupling Capacitors for STM32
Standard

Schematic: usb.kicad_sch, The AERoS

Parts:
C32: 10u; C_0603_1608Metric; MFR. Part # CL10A106MQ8NNNC; JLCPCB Part # C1691
C33: 4u7; C_0603_1608Metric; MFR. Part # CL10A475KP8NNNC; JLCPCB Part # C1705
J9: USB_C_Receptacle_USB2.0_14P; USB_C_Receptacle_G-Switch_GT-USB-7010ASV; MFR. Part # GT-USB-7010ASV; JLCPCB Part # C2988369
R26: 100k; R_0402_1005Metric; MFR. Part # 0402WGF1003TCE; JLCPCB Part # C25741
R27, R28: 5k1; R_0402_1005Metric; MFR. Part # 0402WGF5101TCE; JLCPCB Part # C25905

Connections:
/Microcontroller/USB/USB_D+: J9.A6 (D+), J9.B6 (D+); also elsewhere on the board
/Microcontroller/USB/USB_D-: J9.A7 (D-), J9.B7 (D-); also elsewhere on the board
/Microcontroller/USB/USB_SENSE: R26.2; also elsewhere on the board
GND: C32.2, C33.2, J9.A1 (GND), J9.A12 (GND), J9.B1 (GND), J9.B12 (GND), J9.S1 (SHIELD), R27.2, R28.2; also elsewhere on the board
unnamed: J9.A5 (CC1), R27.1
unnamed: J9.B5 (CC2), R28.1
VBUS: C32.1, C33.1, J9.A4 (VBUS), J9.A9 (VBUS), J9.B4 (VBUS), J9.B9 (VBUS), R26.1; also elsewhere on the board

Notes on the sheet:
USB
USB Connection Circuit
500mA MAX

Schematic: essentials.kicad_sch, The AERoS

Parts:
C29: 100n; C_0402_1005Metric; MFR. Part # CL05B104KO5NNNC; JLCPCB Part # C1525
C30, C31: 30p; C_0402_1005Metric; MFR. Part # 0402CG300J500NT; JLCPCB Part # C1570
J8: Conn_01x03_Pin; PinHeader_1x03_P2.54mm_Vertical_SMD_Pin1Left; MFR. Part # DZ254S-11-03-48; JLCPCB Part # C5160786
R25: 50k; R_0402_1005Metric; MFR. Part # RTT025002FTH; JLCPCB Part # C166559
Y1: 16M; Crystal_SMD_3225-4Pin_3.2x2.5mm; MFR. Part # X322516MMB4SI; JLCPCB Part # C112972

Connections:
+3.3V: J8.1; also elsewhere on the board
/Microcontroller/Essentials/BOOT0: R25.1; also elsewhere on the board
/Microcontroller/Essentials/HSE_IN: C30.1, Y1.1; also elsewhere on the board
/Microcontroller/Essentials/HSE_OUT: C31.1, Y1.3; also elsewhere on the board
/Microcontroller/Essentials/NRST: C29.2; also elsewhere on the board
/Microcontroller/Essentials/SW_BOOT0: J8.2, R25.2
GND: C29.1, C30.2, C31.2, J8.3, Y1.2, Y1.4; also elsewhere on the board

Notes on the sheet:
Booting Circuit
Crystal Oscillator
STM32 Functional Circuits

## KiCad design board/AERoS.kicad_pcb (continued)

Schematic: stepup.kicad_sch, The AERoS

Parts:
C8, C9: 100n; C_0402_1005Metric; MFR. Part # CL05B104KO5NNNC; JLCPCB Part # C1525
C10: 22n; C_0201_0603Metric; MFR. Part # 0201X223K160NT; JLCPCB Part # C285066
C11, C15, C16: 47u; C_1812_4532Metric; MFR. Part # C4532X5R1A476MT000N; JLCPCB Part # C342615
C12: 100u; C_2220_5750Metric; MFR. Part # C5750X5R1A107MT000E; JLCPCB Part # C76692
C13: 22u; C_1210_3225Metric; MFR. Part # CL32A226KAJNNNE; JLCPCB Part # C52306
C14: 4u7; C_0805_2012Metric; MFR. Part # CL21A475KAQNNNE; JLCPCB Part # C1779
C17: 1n; C_0402_1005Metric; MFR. Part # 0402B102K500NT; JLCPCB Part # C1523
L2: 1u; 0806; MFR. Part # BDHE002016081R0MQ1; JLCPCB Part # C702824
Q5: PMOS; DFN-6-2EP_(AGM20P16AS); MFR. Part # AGM20P16AS; JLCPCB Part # C18221388
R16: 121k; R_0402_1005Metric; MFR. Part # 0402WGF1213TCE; JLCPCB Part # C11693
R17: 536k; R_0402_1005Metric; MFR. Part # 0402WGF5363TCE; JLCPCB Part # C68457
R18: 300k; R_0402_1005Metric; MFR. Part # 0402WGF3003TCE; JLCPCB Part # C25774
R19: 44k2; R_0402_1005Metric; MFR. Part # 0402WGF4422TCE; JLCPCB Part # C25895
R20: 78k7; R_0402_1005Metric; MFR. Part # 0402WGF7872TCE; JLCPCB Part # C67239
U3: TPS611781RNWR; RNW0013A; MFR. Part # TPS611781RNWR; JLCPCB Part # C2862009
U4: MCP4552T-104E/MF; DFN8_3x3MC_MCH; MFR. Part # MCP4552T-104E/MF; JLCPCB Part # C623602

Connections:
+3.3V: U4.8 (VDD); also elsewhere on the board
/Microcontroller/SERVO_ON: U3.11 (EN); also elsewhere on the board
/Power/Battery Direct/BATT_OUT: C12.1, C13.1, L2.1, U3.12 (VIN); also elsewhere on the board
/Power/Servo Power/SERVO+: C11.1, C15.1, C16.1, Q5.3 (S), R17.2; also elsewhere on the board
/Power/Servo Power/Step-Up/PREPOT: R17.1, U3.5 (FB), U4.6 (P0B)
GND: C9.1, C11.2, C12.2, C13.2, C14.2, C15.2, C16.2, C17.2, R18.2, R20.2, U3.2 (AGND), U3.6 (PGND), U4.1 (HVC/A0), U4.4 (VSS), U4.5 (P0W), U4.7 (A1), U4.9 (EP); also elsewhere on the board
unnamed: C17.1, R19.2
unnamed: C9.2, C10.1, Q5.1 (D), R16.1, U3.8 (VOUT)
unnamed: C10.2, Q5.2 (G), R16.2, U3.9 (DISDRV)
unnamed: C8.2, U3.13 (BST)
unnamed: R19.1, U3.4 (COMP)
unnamed: R18.1, U3.1 (FREQ_SYNC)
unnamed: R20.1, U3.3 (ILIMIT)
unnamed: C8.1, L2.2, U3.7 (SW)
unnamed: C14.1, U3.10 (VCC)
SCL: U4.2 (SCL); also elsewhere on the board
SDA: U4.3 (SDA); also elsewhere on the board

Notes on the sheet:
6V at 78.7k ohms
Digipot
Servo Power Step-Up
Step-Up Regulator Circuit
I2C Address: 00

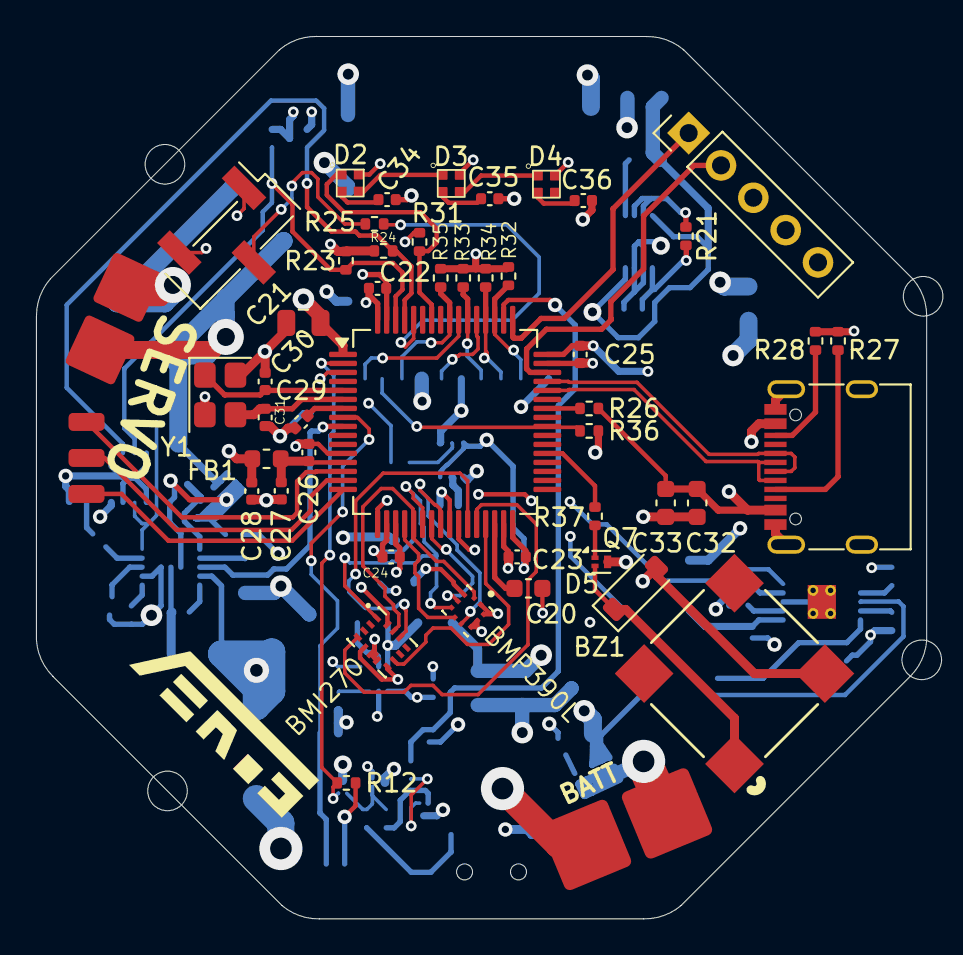
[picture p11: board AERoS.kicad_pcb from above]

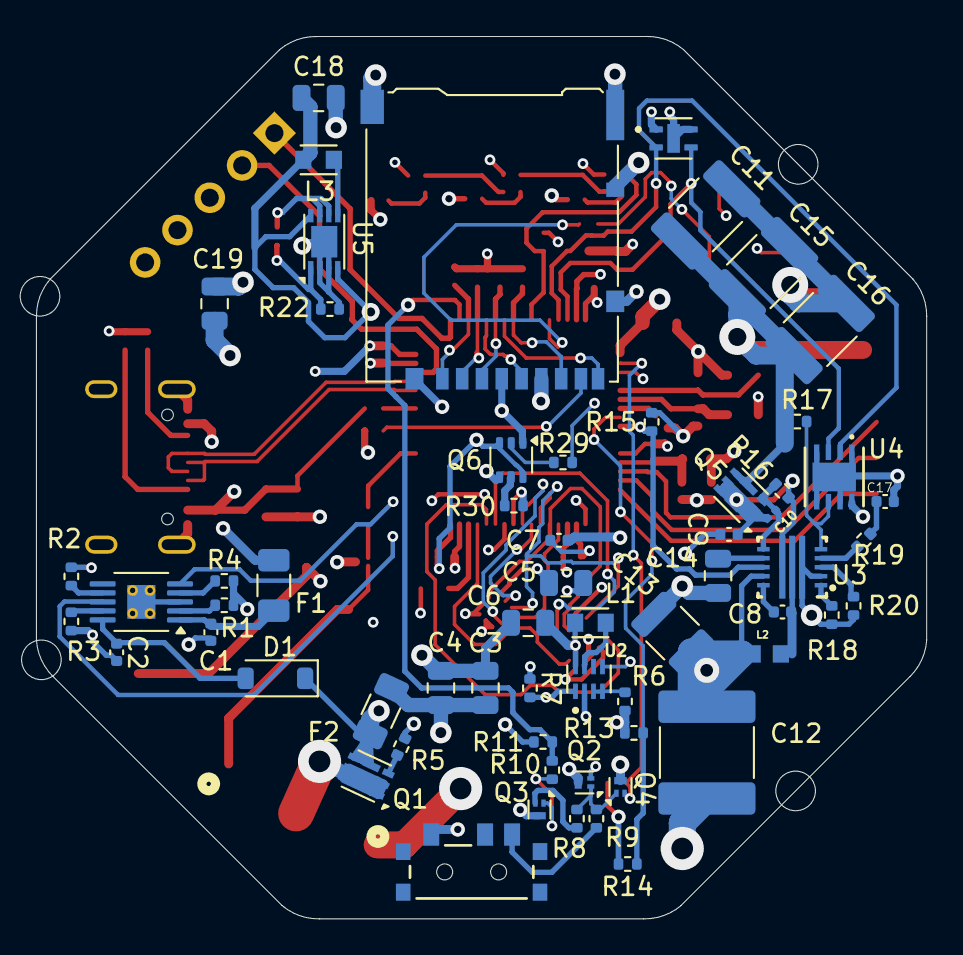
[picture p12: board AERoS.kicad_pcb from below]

Board: 4 copper layers, 49.5 x 49.0 mm, 118 parts (61 on the bottom side), 90 nets.

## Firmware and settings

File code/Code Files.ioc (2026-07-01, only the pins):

Mcu.UserName=STM32F411RETx
PA0-WKUP.GPIO_Label=SERVO1
PA0-WKUP.Signal=S_TIM2_CH1_ETR
PA1.GPIO_Label=SERVO2
PA1.Signal=S_TIM2_CH2
PA10.Signal=GPIO_Analog
PA11.GPIO_Label=USB_D-
PA11.Signal=USB_OTG_FS_DM
PA12.GPIO_Label=USB_D+
PA12.Signal=USB_OTG_FS_DP
PA13.GPIO_Label=SW_DIO
PA13.Signal=SYS_JTMS-SWDIO
PA14.GPIO_Label=SW_CLK
PA14.Signal=SYS_JTCK-SWCLK
PA15.GPIO_Label=KEEP_ON
PA15.Signal=GPIO_Output
PA2.GPIO_Label=SERVO3
PA2.Signal=S_TIM2_CH3
PA3.Signal=GPIO_Analog
PA4.GPIO_Label=BMP_CS
PA4.Signal=GPIO_Output
PA5.GPIO_Label=CLK
PA5.Signal=SPI1_SCK
PA6.GPIO_Label=MISO
PA6.Signal=SPI1_MISO
PA7.GPIO_Label=MOSI
PA7.Signal=SPI1_MOSI
PA8.Signal=GPIO_Analog
PA9.GPIO_Label=USB_SENSE
PA9.Signal=USB_OTG_FS_VBUS
PB0.Signal=GPIO_Analog
PB1.GPIO_Label=IMU_CS
PB1.Signal=GPIO_Output
PB10.GPIO_Label=IMU_INT2
PB10.Signal=GPXTI10
PB12.Signal=GPIO_Analog
PB13.Signal=GPIO_Analog
PB14.Signal=GPIO_Analog
PB15.Signal=GPIO_Analog
PB2.GPIO_Label=IMU_INT1
PB2.Signal=GPXTI2
PB3.GPIO_Label=SD_SW
PB3.Signal=GPXTI3
PB4.GPIO_Label=DAT0
PB4.Signal=SDIO_D0
PB5.GPIO_Label=CHG
PB5.Signal=GPXTI5
PB6.GPIO_Label=LED
PB6.Signal=S_TIM4_CH1
PB7.GPIO_Label=PG
PB7.Signal=GPXTI7
PB8.GPIO_Label=SCL
PB8.Signal=I2C1_SCL
PB9.GPIO_Label=SDA
PB9.Signal=I2C1_SDA
PC0.GPIO_Label=VSENSE
PC0.Signal=ADCx_IN10
PC1.GPIO_Label=SERVO_ON
PC1.Signal=GPIO_Output
PC10.GPIO_Label=DAT2
PC10.Signal=SDIO_D2
PC11.GPIO_Label=DAT3
PC11.Signal=SDIO_D3
PC12.GPIO_Label=SD_CLK
PC12.Signal=SDIO_CK
PC13-ANTI_TAMP.GPIO_Label=POWER_TOGGLE
PC13-ANTI_TAMP.Signal=GPXTI13
PC14-OSC32_IN.GPIO_Label=SD_ON
PC14-OSC32_IN.Signal=GPIO_Output
PC15-OSC32_OUT.Signal=GPIO_Analog
PC2.Signal=GPIO_Analog
PC3.Signal=GPIO_Analog
PC4.GPIO_Label=BMP_INT
PC4.Signal=GPXTI4
PC5.GPIO_Label=SENSE_ON
PC5.Signal=GPIO_Output
PC6.GPIO_Label=BUZZ
PC6.Signal=S_TIM3_CH1
PC7.Signal=GPIO_Analog
PC8.Signal=GPIO_Analog
PC9.GPIO_Label=DAT1
PC9.Signal=SDIO_D1
PD2.GPIO_Label=SD_CMD
PD2.Signal=SDIO_CMD

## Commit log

2026-07-01 AERoS v0 prototype, hardware only, untested
    [5v.kicad_sch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]
2026-07-01 Revise schematic diagram in README
    Updated the schematic diagram in the README to improve clarity and correctness.
